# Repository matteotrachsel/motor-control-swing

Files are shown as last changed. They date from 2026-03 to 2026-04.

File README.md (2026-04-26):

# ESP32 Baby Swing Controller

An ESP32-based motor controller for a baby swing. The motor drives a crank
mechanism that converts continuous rotation into a back-and-forth swing motion.
A built-in Progressive Web App (PWA) lets any phone, tablet, or desktop on the
same WiFi network control the swing — no app store required.

The device advertises itself as **`http://rockbox.local`** on your local network.

---

## Features

- **WebSocket real-time control** — low-latency commands and live state sync
  across all connected devices simultaneously
- **Progressive Web App** — installable on Android and iOS home screens; runs
  full-screen with no browser chrome
- **mDNS hostname** — reach the UI at `http://rockbox.local` without
  memorising an IP address
- **Speed control** — adjustable swing speed via a dial (5–80 %)
- **Hard speed cap** — firmware enforces an 80 % PWM ceiling that cannot be
  overridden remotely
- **Rocking patterns** — choose between Steady, Wave, and Lull to vary the
  motion over time
- **Kick-start** — optional boost pulse on startup to overcome crank stiction
- **Auto-stop timer** — configurable run timer (15, 30, 45, or 60 minutes);
  persisted across device restarts
- **Physical button** — hardware toggle on GPIO 18 starts or stops the swing
  without opening the app
- **Manual motor control** — forward/reverse jog in the setup panel, useful
  during installation or maintenance
- **Emergency stop** — always-visible stop button; also accessible via HTTP GET
  `/stop` as a fallback if WebSocket fails
- **WiFi auto-reconnect** — connection is checked every 10 seconds; the ESP32
  reconnects automatically on link loss
- **WiFi setup portal** — captive portal in AP mode for first-time WiFi
  configuration; no hard-coded credentials needed
- **Over-the-air updates** — automatic check against the GitHub release on boot,
  plus a manual upload page at `/update`
- **Dark / light theme** — toggle from the setup panel
- **Motion history** — 30-minute rolling activity graph in the UI

---

## Hardware

### Bill of Materials

| Component | Notes |
|---|---|
| ESP32 development board | Any standard 38-pin ESP32 DevKit |
| L298N motor driver module | Must have the 5 V regulator jumper installed |
| 12 V DC motor | Sized for your swing's crank load |
| 12 V power supply | Current rating matched to motor stall current |
| Connecting wire | — |
| Momentary push button (optional) | For the physical GPIO 18 toggle |

### Wiring

| ESP32 GPIO | L298N pin | Notes |
|---|---|---|
| GPIO 25 | IN1 | Motor direction A |
| GPIO 26 | IN2 | Motor direction B |
| GPIO 27 | ENA | PWM speed signal |
| — | +12 V | From 12 V PSU |
| — | GND | Shared with ESP32 GND |
| VIN (5 V) | 5 V out | L298N onboard regulator powers the ESP32 |
| OUT1 / OUT2 | — | To DC motor terminals |
| GPIO 18 | — | Optional push button to GND (INPUT_PULLUP) |

> All GND pins must be connected together: PSU ground, L298N ground, and ESP32
> ground.

### CAD Files

The `CAD/` folder contains STL and STEP files for 3D-printable mounting
brackets and crank components.

---

## Software Setup

### Prerequisites

- [Visual Studio Code](https://code.visualstudio.com/)
- [PlatformIO IDE extension](https://platformio.org/install/ide?install=vscode)

### Steps

1. **Clone or download** the repository and open the project folder in VS Code.
   PlatformIO will detect `platformio.ini` automatically.

2. **Build and flash** — connect the ESP32 via USB, then click **Upload** in
   the PlatformIO toolbar (or run `pio run --target upload`). PlatformIO
   auto-detects the serial port. To pin a specific port, uncomment the
   `upload_port` line in `platformio.ini`.

3. **Open the Serial Monitor** at 115200 baud to confirm the device boots.

4. **First-time WiFi setup** — on first boot (or after a WiFi reset) the
   device starts in AP mode. See [WiFi Setup](#wifi-setup) below.

> WiFi credentials are stored in NVS (non-volatile storage) and survive
> power cycles. You do not need to hard-code them in `src/main.cpp`.

---

## WiFi Setup

When no WiFi credentials are stored, the device boots into AP (access point)
mode:

1. A network named **`RockBox-Setup`** appears in your WiFi list. Connect
   to it (no password required).
2. A captive portal opens automatically on Android and iOS. If it does not,
   open a browser and go to `http://192.168.4.1`.
3. Tap **Scan** to list nearby networks, select yours, enter the password, and
   tap **Connect & Save**.
4. The device reboots, joins your network, and is accessible at
   `http://rockbox.local`.

To reset WiFi credentials later, open the setup panel (gear icon) in the web
UI and tap **Reset WiFi**, or navigate to `http://rockbox.local/reset-wifi`.

---

## Usage

### Accessing the Web UI

After the ESP32 boots and connects to WiFi, the web interface is available at:

- `http://rockbox.local` — works on most devices without needing the IP
- `http://<ip-address>` — the assigned IP is printed in the Serial Monitor at
  startup

### Installing as a PWA

**Android (Chrome):**
1. Open `http://rockbox.local` in Chrome.
2. Tap the three-dot menu and choose **Add to Home screen** (or tap the
   **Install app** banner that appears at the top of the page).
3. The app opens full-screen from your home screen with no browser bar.

**iOS (Safari):**
1. Open `http://rockbox.local` in Safari.
2. Tap the share button (box with arrow), then **Add to Home Screen**.
3. The app opens full-screen from your home screen.

### Swing Mode

Tap the large circular button to start the swing. The motor runs continuously
in the forward direction; the crank mechanism converts that rotation into
back-and-forth motion. Tap the button again to stop.

The button glows and shows a spinning icon while the motor is running. All
connected devices see the same state in real time.

The physical button on GPIO 18 (if wired) also toggles the swing without
opening the app.

### Speed Dial

The dial sets the motor speed as a percentage (5–80 %). Adjusting it while the
swing is running sends an update immediately (with debouncing). Adjusting it
while the swing is stopped sets the speed for the next start.

### Rocking Patterns

Three patterns are available from the pattern row below the dial:

| Pattern | Behaviour |
|---|---|
| **Steady** | Constant speed — motor runs at exactly the set percentage |
| **Wave** | Sinusoidal variation ±25 % around the target, cycling roughly every 4 seconds |
| **Lull** | Gradual slowdown from full target speed to ~50 % over approximately 5 minutes |

### Auto-stop Timer

Tap a duration button (15, 30, 45, or 60 min) to set a run timer. The
countdown appears in the UI. When the timer elapses the motor stops
automatically. Tap **Off** to disable the timer. The last-set value is
persisted and used for all future sessions.

### Kick-start

Some crank positions require extra torque to get moving. The kick-start feature
fires a brief high-power pulse (60–100 % PWM for 200 ms–1 s) at startup before
dropping to the normal run speed. Configure it in the setup panel (gear icon)
or leave it **Off** if the motor starts reliably without it.

### Manual Control

Open the setup panel (gear icon) and use the **Fwd / Stop / Rev** buttons to
drive the motor directly. This bypasses swing mode and is intended for
installation testing or maintenance. Swing mode is automatically cancelled when
a manual command is sent.

### Emergency Stop

The red **Emergency Stop** button is always visible at the bottom of the
screen. It sends a `stop` command over WebSocket. The HTTP endpoint
`GET /stop` provides the same result if the WebSocket connection is unavailable.

---

## Firmware Updates

### Automatic (on boot)

On every boot the device fetches `version.txt` from the GitHub repository. If
the remote version is newer than the running firmware it downloads
`firmware.bin` from the latest GitHub Release and flashes it automatically,
then reboots.

### Manual upload

Navigate to `http://rockbox.local/update` (credentials: **admin** /
**babyswing** — change `OTA_PASS` in `src/main.cpp` before deploying).

- **Check GitHub for update** — triggers the same automatic check on demand.
- **Upload & Flash** — upload a `.bin` file built with PlatformIO to flash
  immediately.

---

## API / WebSocket Protocol

Connect to `ws://<device-ip>:81`.

### Commands (client → ESP32)

All commands are plain-text strings.

| Command | Arguments | Description |
|---|---|---|
| `heartbeat` | — | Keeps the session alive. The PWA sends this automatically every 15 seconds. |
| `swing_start` | `[speed]` (integer, optional) | Starts the swing. If speed is omitted the last-set swing speed is used. Clamped to 5–80 %. |
| `swing_stop` | — | Stops the motor and clears swing mode. |
| `set_speed` | `speed` (integer) | Updates swing speed. Takes effect immediately if running. Clamped to 5–80 %. |
| `set` | `dir` (`forward`/`reverse`/`stop`) `speed` | Manual motor override. Cancels swing mode. Speed clamped to 0–80 %. |
| `set_timer` | `minutes` (integer, 0–240) | Sets the auto-stop timer duration. 0 disables the timer. |
| `set_kick` | `pct` (0–100) `ms` (50–2000) | Configures the kick-start pulse level and duration. |
| `set_pattern` | `pattern` (`wave`/`steady`/`lull`) | Sets the rocking pattern. |
| `stop` | — | Hard stop — halts the motor and cancels swing mode. |

Examples:

```
swing_start 50
set_speed 60
set forward 30
set_timer 30
set_kick 80 400
set_pattern wave
heartbeat
stop
```

### State Broadcast (ESP32 → all clients)

The ESP32 broadcasts the current state to every connected client after any
command and when clients connect or disconnect.

```json
{
  "swing":     false,
  "speed":     0,
  "dir":       "stop",
  "swingSpd":  40,
  "clients":   1,
  "timerMins": 30,
  "timerSec":  1800,
  "kickPct":   80,
  "kickMs":    400,
  "pattern":   "steady",
  "fw":        34
}
```

| Field | Type | Description |
|---|---|---|
| `swing` | boolean | Whether swing mode is active |
| `speed` | integer | Current motor speed in % (0 when stopped) |
| `dir` | string | Current motor direction: `"forward"`, `"reverse"`, or `"stop"` |
| `swingSpd` | integer | Speed percentage used on the next `swing_start` |
| `clients` | integer | Number of connected WebSocket clients |
| `timerMins` | integer | Configured auto-stop duration in minutes (0 = disabled) |
| `timerSec` | integer | Seconds remaining on the active timer; −1 if no timer is running |
| `kickPct` | integer | Kick-start boost level in % (0 = disabled) |
| `kickMs` | integer | Kick-start pulse duration in milliseconds |
| `pattern` | string | Active rocking pattern: `"steady"`, `"wave"`, or `"lull"` |
| `fw` | integer | Running firmware version number |

---

## Safety Features

### Hard Speed Cap

The firmware clamps all speed values to a maximum of **80 %** PWM duty cycle
via `constrain()` in `applyMotor()`. This cap is enforced in firmware and
cannot be raised through any WebSocket command.

### Auto-stop Timer

The run timer is the primary automatic shutoff mechanism. Set a duration in the
UI; when it elapses the motor stops and the timer resets. If no timer is set the
motor runs until manually stopped.

### WiFi Loss

If the WiFi connection drops, the ESP32 attempts to reconnect every 10 seconds
in the main loop. The motor continues running during a dropout and stops only
if the auto-stop timer fires.

If the ESP32 fails to connect to WiFi at boot, it falls back to AP setup mode.

---

## Architecture

The entire stack runs on the ESP32 — there is no separate server.

| Component | Detail |
|---|---|
| HTTP server | Port 80 — serves the HTML page, PWA manifest, SVG icon, `/stop`, `/update`, `/reset-wifi`, and `/ota-github` endpoints |
| WebSocket server | Port 81 — handles all real-time motor commands and state broadcasts |
| mDNS | Advertises `rockbox.local` on the local network |
| NVS (Preferences) | Persists swing speed, timer, kick-start config, and WiFi credentials across power cycles |
| PWA | HTML, CSS, JavaScript, manifest, and icon are all stored in flash as `PROGMEM` strings — no filesystem required |
| OTA engine | Compares running firmware version against `version.txt` on GitHub; downloads and flashes `firmware.bin` if newer |

### PWM Configuration

| Parameter | Value |
|---|---|
| Channel | 0 |
| Frequency | 5 kHz |
| Resolution | 8-bit (0–255) |

### Compile-time Configuration

The following constants near the top of `src/main.cpp` can be changed before
flashing:

| Constant | Default | Description |
|---|---|---|
| `HOSTNAME` | `"rockbox"` | mDNS hostname (`http://<HOSTNAME>.local`) |
| `FW_VERSION` | integer | Firmware version; increment when creating a release |
| `OTA_USER` | `"admin"` | Username for the `/update` page |
| `OTA_PASS` | `"babyswing"` | Password for the `/update` page — **change this** |
| `AP_SSID` | `"RockBox-Setup"` | SSID broadcast in AP setup mode |

### Runtime Settings (persisted in NVS)

| Setting | Range | Default |
|---|---|---|
| Swing speed | 5–80 % | 40 % |
| Auto-stop timer | 0–240 min | 0 (disabled) |
| Kick-start level | 0–100 % | 0 (disabled) |
| Kick-start duration | 50–2000 ms | 400 ms |
| Rocking pattern | steady / wave / lull | steady |

---

## Automated Builds

A GitHub Actions workflow (`.github/workflows/firmware-release.yml`) builds
`firmware.bin` automatically when a new Git tag is pushed. The resulting binary
is attached to the GitHub Release and served as the OTA target for all devices.

To release a new version:
1. Increment `FW_VERSION` in `src/main.cpp` and update `version.txt` to the
   same number.
2. Commit, tag (`git tag v<N>`), and push the tag.
3. The workflow builds the firmware and creates the release automatically.

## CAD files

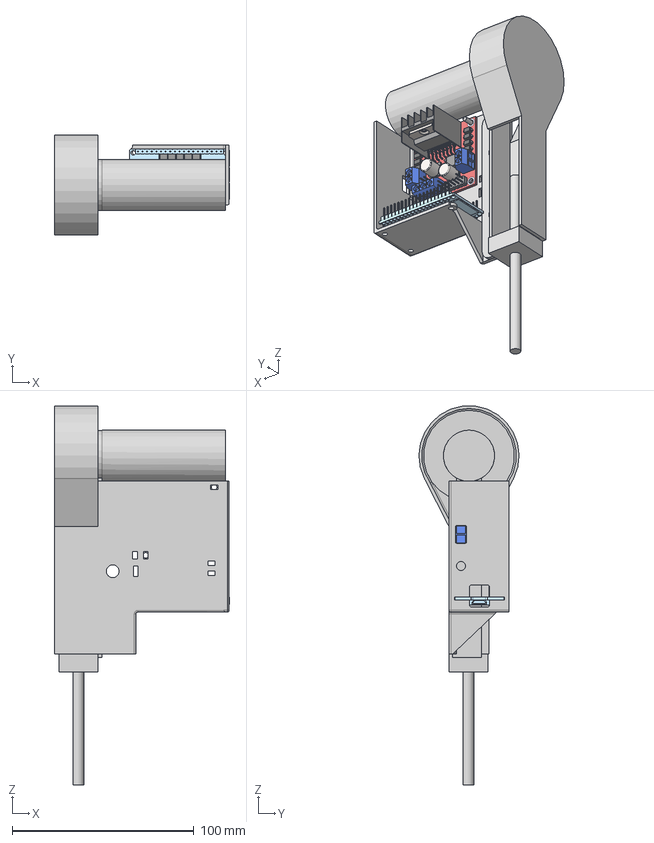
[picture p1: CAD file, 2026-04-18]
CAD/babywippe (Assembly).step
96.2 x 55.1 x 208.3 mm

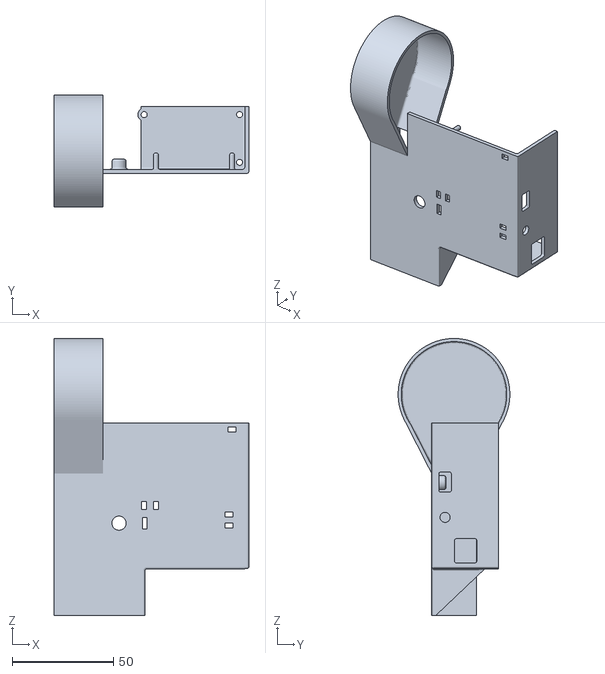
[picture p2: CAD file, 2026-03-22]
CAD/housingFull.stl
96.0 x 55.1 x 136.5

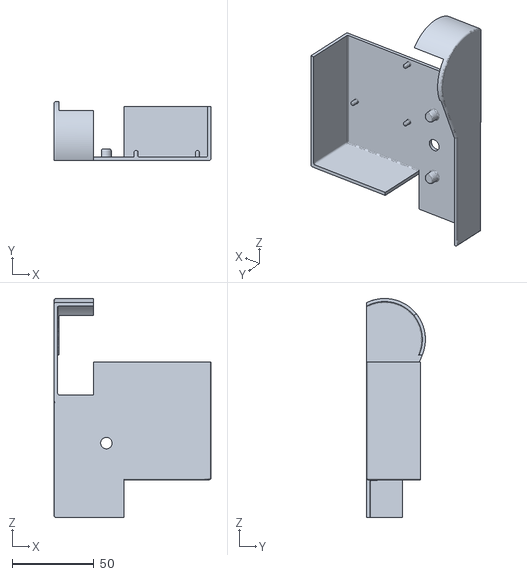
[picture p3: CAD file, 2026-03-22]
CAD/Body1.stl
96.0 x 36.0 x 134.0

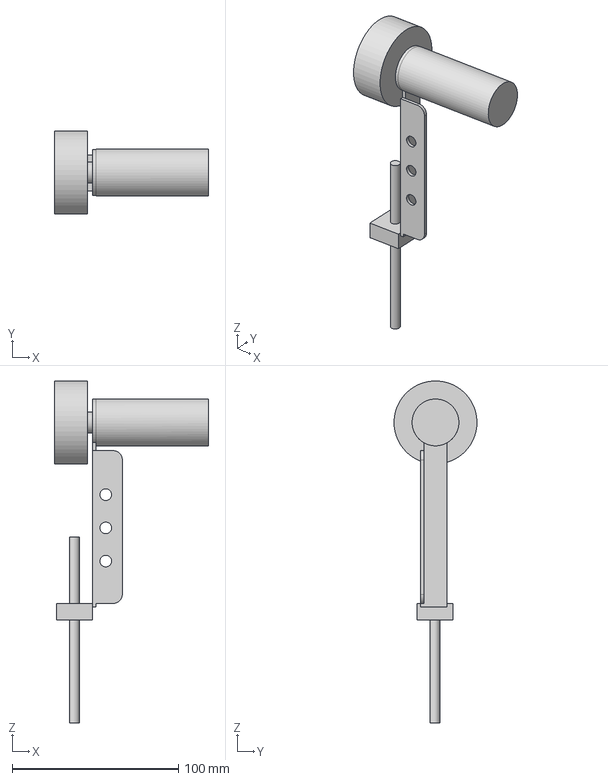
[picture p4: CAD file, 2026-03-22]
CAD/babywippe.step
93.0 x 50.0 x 206.0 mm

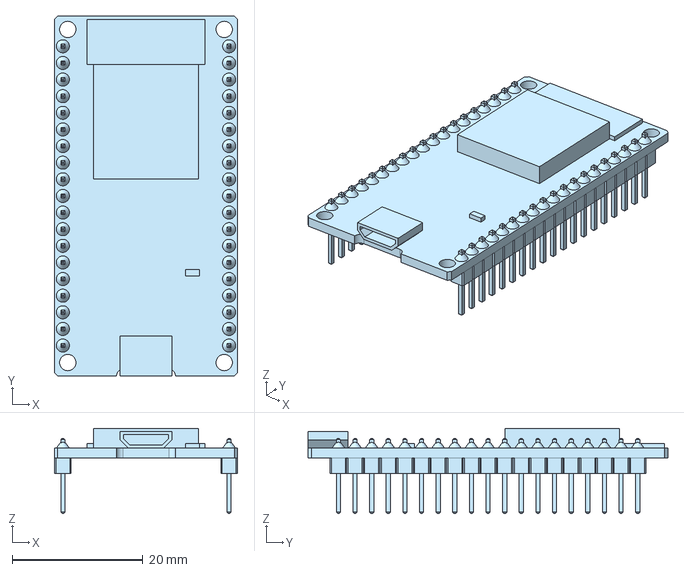
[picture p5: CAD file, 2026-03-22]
CAD/ESP32.step
28.0 x 55.0 x 13.0 mm

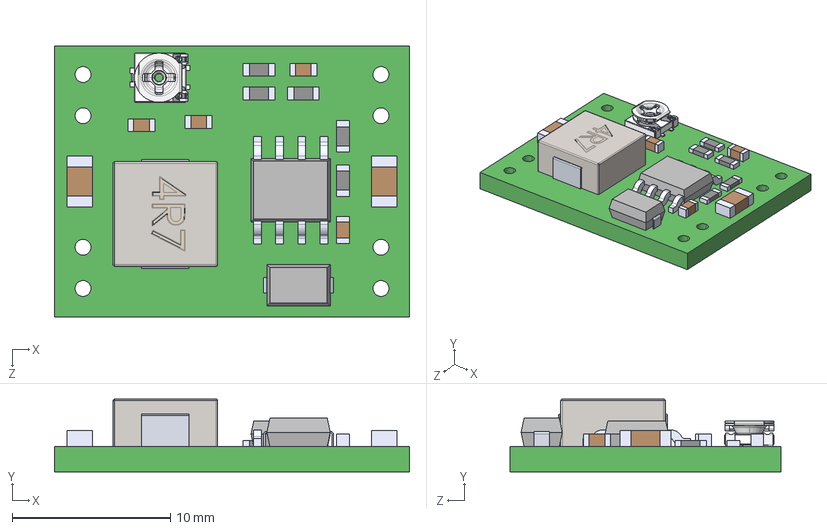
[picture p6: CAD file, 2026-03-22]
CAD/DC_DC_MP1584EN_Step_Down.STEP
22.4 x 4.60 x 17.1 mm
PCB, DC-DC 4.5-28V to 0.8-20V Output 3A MP1584EN Step Down Buck Converter
MP1584EN CHIP, DC-DC 4.5-28V to 0.8-20V Output 3A MP1584EN Step Down Buck Converter
INDUCTOR, DC-DC 4.5-28V to 0.8-20V Output 3A MP1584EN Step Down Buck Converter
SCHOTTKY DIODE, DC-DC 4.5-28V to 0.8-20V Output 3A MP1584EN Step Down Buck Converter
LARGE SMD CAPACITOR, DC-DC 4.5-28V to 0.8-20V Output 3A MP1584EN Step Down Buck Converter x 2
SMD RESISTOR, 104, DC-DC 4.5-28V to 0.8-20V Output 3A MP1584EN Step Down Buck Converter x 4
SMD RESISTOR, 822, DC-DC 4.5-28V to 0.8-20V Output 3A MP1584EN Step Down Buck Converter
SMALL SMD CAPACITOR, DC-DC 4.5-28V to 0.8-20V Output 3A MP1584EN Step Down Buck Converter x 4
POTENTIOMETER, DC-DC 4.5-28V to 0.8-20V Output 3A MP1584EN Step Down Buck Converter

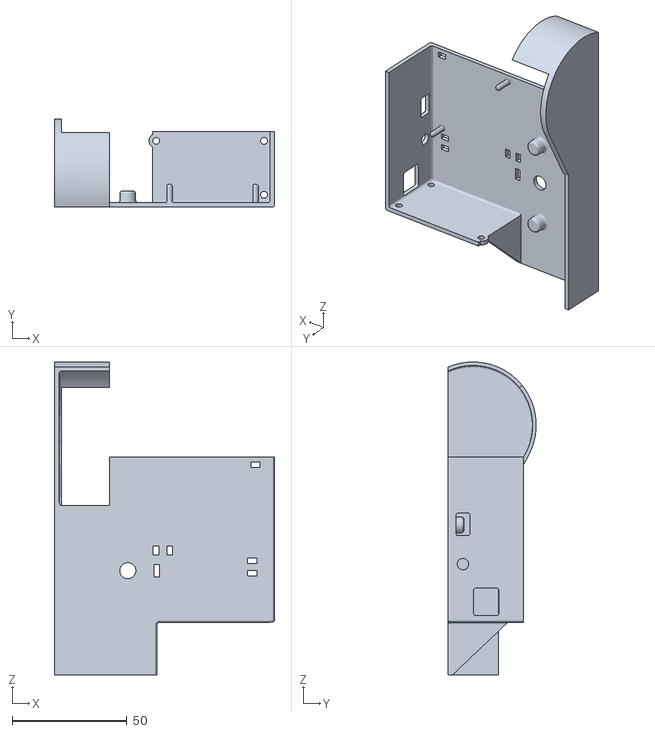
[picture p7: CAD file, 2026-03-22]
CAD/housing_2.stl
96.0 x 38.5 x 136.5

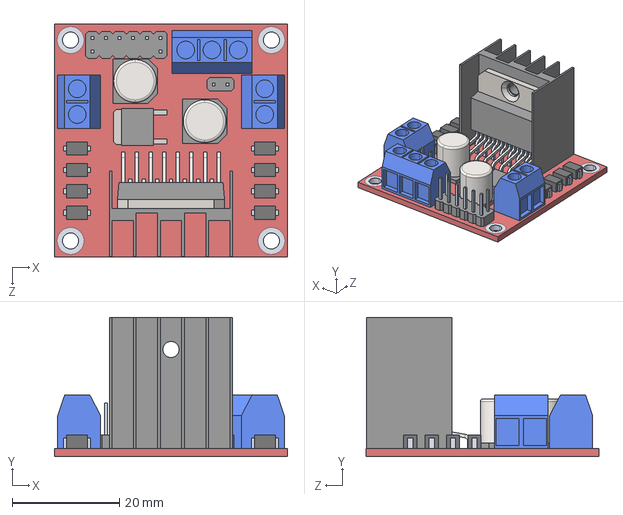
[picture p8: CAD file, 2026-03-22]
CAD/L298N Motor Driver.STEP
43.5 x 26.0 x 43.5 mm

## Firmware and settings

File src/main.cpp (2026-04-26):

/*
 * ============================================================
 *  ESP32 RockBox Controller
 * ============================================================
 *
 *  Motor drives a linear axis via crank — always spins in one
 *  direction. Swing ON = motor runs at set speed. The crank
 *  converts continuous rotation into back-and-forth swing.
 *
 *  Hardware:
 *    12V Adapter  ──▶  L298N +12V & GND
 *    L298N 5V out ──▶  ESP32 VIN  (5V jumper on L298N)
 *    GPIO 25  ──▶  L298N IN1
 *    GPIO 26  ──▶  L298N IN2
 *    GPIO 27  ──▶  L298N ENA  (PWM speed)
 *    OUT1/OUT2 ──▶  DC Motor
 *    All GNDs connected together!
 *
 *  Access from any device on your WiFi:
 *    http://rockbox.local   (or the IP shown in Serial Monitor)
 *
 *  WebSocket port: 81  (HTTP port: 80)
 *
 * ============================================================
 */

#include <Arduino.h>
#include <WiFi.h>
#include <WebServer.h>
#include <WebSocketsServer.h>
#include <ESPmDNS.h>
#include <Preferences.h>
#include <DNSServer.h>
#include <HTTPClient.h>
#include <WiFiClientSecure.h>
#include <HTTPUpdate.h>
#include <Update.h>

// ─── Network config ───────────────────────────────────────────
// WiFi credentials are stored in NVS (set via AP setup portal).
const char *HOSTNAME = "rockbox";      // → http://rockbox.local
const char *AP_SSID = "RockBox-Setup"; // AP mode SSID (open)
// ─────────────────────────────────────────────────────────────

// ─── Firmware version & OTA URLs ─────────────────────────────
// Increment FW_VERSION each release. Commit version.txt with the
// same number to the master branch. Create a GitHub Release and
// upload firmware.bin as an asset named "firmware.bin".
const int FW_VERSION = 35;
const char *GITHUB_VER_URL = "https://raw.githubusercontent.com/matteotrachsel/motor-control-swing/main/version.txt";
const char *GITHUB_BIN_URL = "https://github.com/matteotrachsel/motor-control-swing/releases/latest/download/firmware.bin";
// ─── Manual /update page credentials ─────────────────────────
const char *OTA_USER = "admin";
const char *OTA_PASS = "babyswing"; // change to something personal
// ─────────────────────────────────────────────────────────────

// ─── Motor driver pins ───────────────────────────────────────
const int PIN_IN1 = 25;
const int PIN_IN2 = 26;
const int PIN_ENA = 27; // PWM speed

// ─── Physical toggle button ──────────────────────────────────
const int PIN_BTN = 18; // INPUT_PULLUP — connect one pin pair to GND

// ─── PWM ─────────────────────────────────────────────────────
const int PWM_CH = 0;
const int PWM_FREQ = 5000;
const int PWM_BITS = 8; // 0–255

// ─── Safety limits ───────────────────────────────────────────
const int MAX_SPEED_PCT = 100; // hard cap — never exceeded

// ─── Motor state ─────────────────────────────────────────────
enum MotorDir
{
  MSTOP,
  MFWD,
  MREV
};
int g_spd = 0;
MotorDir g_dir = MSTOP;

// ─── Swing state ─────────────────────────────────────────────
// Motor always runs in one direction — crank handles oscillation.
// Swing ON = motor running; Swing OFF = motor stopped.
bool g_swinging = false;
int g_swingSpd = 40; // % to use when swing starts

// ─── Watchdog ────────────────────────────────────────────────
int g_clients = 0;
ulong g_lastAct = 0;

// ─── Run timer ───────────────────────────────────────────────
int g_timerMins = 0;  // 0 = no timer; >0 = run this many minutes then stop
ulong g_timerEnd = 0; // millis() when timer fires; 0 = no active timer

// ─── Kick-start (start boost) ─────────────────────────
int g_kickPct = 0;   // boost % — 0 = off; typical: 60, 80, 100
int g_kickMs = 400;  // boost duration ms — typical: 200, 400, 600, 1000
ulong g_kickEnd = 0; // millis() when kick pulse ends; 0 = not kicking

// ─── Rocking pattern ──────────────────────────────────
// "steady" = constant speed
// "wave"   = sinusoidal speed variation (rhythmic)
// "lull"   = gradual slowdown to help baby fall asleep
String g_pattern = "steady";
float  g_wavePhase  = 0.0f;  // advances each pattern tick
float  g_lullFactor = 1.0f;  // 1.0 → 0.5 over ~5 min

WebServer httpSrv(80);
WebSocketsServer wsSrv(81);
Preferences prefs;
DNSServer dnsServer;
bool g_apMode = false; // true = running WiFi config portal

// ════════════════════════════════════════════════════════════
//  MOTOR
// ════════════════════════════════════════════════════════════

void applyMotor(MotorDir dir, int pct)
{
  pct = constrain(pct, 0, MAX_SPEED_PCT);
  g_dir = dir;
  g_spd = (dir == MSTOP) ? 0 : pct;

  if (dir == MFWD)
  {
    digitalWrite(PIN_IN1, HIGH);
    digitalWrite(PIN_IN2, LOW);
  }
  else if (dir == MREV)
  {
    digitalWrite(PIN_IN1, LOW);
    digitalWrite(PIN_IN2, HIGH);
  }
  else
  {
    digitalWrite(PIN_IN1, LOW);
    digitalWrite(PIN_IN2, LOW);
  }

  ledcWrite(PWM_CH, (dir == MSTOP) ? 0 : map(pct, 0, 100, 0, 255));
  Serial.printf("[Motor] %s %d%%\n",
                dir == MFWD ? "FWD" : dir == MREV ? "REV"
                                                  : "STOP",
                g_spd);
}

void applyMotorRaw(MotorDir dir, int pct)
{
  pct = constrain(pct, 0, 100);
  g_dir = dir;
  g_spd = (dir == MSTOP) ? 0 : pct;
  if (dir == MFWD)
  {
    digitalWrite(PIN_IN1, HIGH);
    digitalWrite(PIN_IN2, LOW);
  }
  else if (dir == MREV)
  {
    digitalWrite(PIN_IN1, LOW);
    digitalWrite(PIN_IN2, HIGH);
  }
  else
  {
    digitalWrite(PIN_IN1, LOW);
    digitalWrite(PIN_IN2, LOW);
  }
  ledcWrite(PWM_CH, (dir == MSTOP) ? 0 : map(pct, 0, 100, 0, 255));
  Serial.printf("[Kick] RAW FWD %d%%\n", pct);
}

void hardStop()
{
  g_swinging = false;
  g_timerEnd = 0;
  g_kickEnd = 0;
  applyMotor(MSTOP, 0);
}

// ════════════════════════════════════════════════════════════
//  STATE JSON
// ════════════════════════════════════════════════════════════

const char *dirStr(MotorDir d)
{
  return d == MFWD ? "forward" : d == MREV ? "reverse"
                                           : "stop";
}

String stateJSON()
{
  ulong now2 = millis();
  int timerSec = -1;
  if (g_timerEnd != 0 && g_swinging)
    timerSec = (g_timerEnd > now2) ? (int)((g_timerEnd - now2) / 1000) : 0;
  char buf[320];
  snprintf(buf, sizeof(buf),
           "{\"swing\":%s,\"speed\":%d,\"dir\":\"%s\","
           "\"swingSpd\":%d,\"clients\":%d,"
           "\"timerMins\":%d,\"timerSec\":%d,"
           "\"kickPct\":%d,\"kickMs\":%d,"
           "\"pattern\":\"%s\","
           "\"fw\":%d}",
           g_swinging ? "true" : "false",
           g_spd, dirStr(g_dir),
           g_swingSpd, g_clients,
           g_timerMins, timerSec,
           g_kickPct, g_kickMs,
           g_pattern.c_str(),
           FW_VERSION);
  return String(buf);
}

void broadcast()
{
  String s = stateJSON();
  wsSrv.broadcastTXT(s);
}

void saveSettings()
{
  prefs.begin("swing", false);
  prefs.putInt("swingSpd", g_swingSpd);
  prefs.putInt("timerMins", g_timerMins);
  prefs.putInt("kickPct", g_kickPct);
  prefs.putInt("kickMs", g_kickMs);
  prefs.putString("pattern", g_pattern);
  prefs.end();
  Serial.println("[NVS] settings saved");
}

// ─── WiFi credential NVS helpers ─────────────────────────────

bool loadWifiCreds(String &ssid, String &pass)
{
  prefs.begin("wifi", true);
  ssid = prefs.getString("ssid", "");
  pass = prefs.getString("pass", "");
  prefs.end();
  return ssid.length() > 0;
}

void saveWifiCreds(const String &ssid, const String &pass)
{
  prefs.begin("wifi", false);
  prefs.putString("ssid", ssid);
  prefs.putString("pass", pass);
  prefs.end();
  Serial.println("[NVS] WiFi credentials saved");
}

void clearWifiCreds()
{
  prefs.begin("wifi", false);
  prefs.remove("ssid");
  prefs.remove("pass");
  prefs.end();
  Serial.println("[NVS] WiFi credentials cleared");
}

// ─── Helper: escape a string for JSON output ─────────────────
static String jsonEsc(const String &s)
{
  String r;
  r.reserve(s.length());
  for (size_t i = 0; i < s.length(); i++)
  {
    char c = s.charAt(i);
    if (c == '"')
      r += "\\\"";
    else if (c == '\\')
      r += "\\\\";
    else if (c < 0x20)
      r += ' ';
    else
      r += c;
  }
  return r;
}

// ════════════════════════════════════════════════════════════
//  MINI JSON VALUE EXTRACTOR
// ════════════════════════════════════════════════════════════

String jval(const char *json, const char *key)
{
  String s(json);
  String k = String("\"") + key + "\":";
  int i = s.indexOf(k);
  if (i < 0)
    return "";
  i += k.length();
  while (i < (int)s.length() && s[i] == ' ')
    i++;
  bool quoted = (s[i] == '"');
  if (quoted)
  {
    i++;
    int j = s.indexOf('"', i);
    return j < 0 ? "" : s.substring(i, j);
  }
  int j = i;
  while (j < (int)s.length() && s[j] != ',' && s[j] != '}')
    j++;
  return s.substring(i, j);
}

// ════════════════════════════════════════════════════════════
//  WEBSOCKET EVENTS
// ════════════════════════════════════════════════════════════

void onWsEvent(uint8_t num, WStype_t type, uint8_t *payload, size_t length)
{
  if (type == WStype_CONNECTED)
  {
    g_clients++;
    g_lastAct = millis();
    Serial.printf("[WS] +client #%u  total=%d\n", num, g_clients);
    String s = stateJSON();
    wsSrv.sendTXT(num, s);
    broadcast();
    return;
  }
  if (type == WStype_DISCONNECTED)
  {
    g_clients = max(0, g_clients - 1);
    Serial.printf("[WS] -client #%u  total=%d\n", num, g_clients);
    broadcast();
    return;
  }
  if (type != WStype_TEXT)
    return;

  g_lastAct = millis();
  const char *p = (const char *)payload;
  String cmd = jval(p, "cmd");

  if (cmd == "heartbeat")
  {
    // g_lastAct updated above
  }
  else if (cmd == "swing_start")
  {
    String s = jval(p, "speed");
    if (s.length())
      g_swingSpd = constrain(s.toInt(), 5, MAX_SPEED_PCT);
    g_swinging = true;
    g_wavePhase  = 0.0f;   // reset pattern state
    g_lullFactor = 1.0f;
    if (g_timerMins > 0)
      g_timerEnd = millis() + (ulong)g_timerMins * 60000UL;
    else
      g_timerEnd = 0;
    if (g_kickPct > 0 && g_kickPct > g_swingSpd)
    {
      applyMotorRaw(MFWD, g_kickPct);
      g_kickEnd = millis() + (ulong)g_kickMs;
      Serial.printf("[Kick] %d%% for %dms → run %d%%\n", g_kickPct, g_kickMs, g_swingSpd);
    }
    else
    {
      g_kickEnd = 0;
      applyMotor(MFWD, g_swingSpd);
    }
    broadcast();
    Serial.printf("[Swing] START  spd=%d%%  timer=%dmin\n", g_swingSpd, g_timerMins);
  }
  else if (cmd == "swing_stop")
  {
    hardStop();
    broadcast();
    Serial.println("[Swing] STOP");
  }
  else if (cmd == "set")
  {
    // Manual override (useful for setup / testing direction)
    g_swinging = false;
    String d = jval(p, "dir");
    String s = jval(p, "speed");
    MotorDir dir = MSTOP;
    if (d == "forward")
      dir = MFWD;
    else if (d == "reverse")
      dir = MREV;
    applyMotor(dir, s.length() ? s.toInt() : 0);
    broadcast();
  }
  else if (cmd == "set_speed")
  {
    String s = jval(p, "speed");
    if (s.length())
    {
      g_swingSpd = constrain(s.toInt(), 5, MAX_SPEED_PCT);
      if (g_swinging)
        applyMotor(MFWD, g_swingSpd);
      saveSettings();
      broadcast();
    }
  }
  else if (cmd == "stop")
  {
    hardStop();
    broadcast();
  }
  else if (cmd == "set_timer")
  {
    String m = jval(p, "minutes");
    if (m.length())
    {
      g_timerMins = constrain(m.toInt(), 0, 240);
      if (g_swinging)
      {
        if (g_timerMins > 0)
          g_timerEnd = millis() + (ulong)g_timerMins * 60000UL;
        else
          g_timerEnd = 0;
      }
      saveSettings();
      broadcast();
      Serial.printf("[Timer] set to %d min\n", g_timerMins);
    }
  }
  else if (cmd == "set_kick")
  {
    String kPct = jval(p, "pct");
    String kMs = jval(p, "ms");
    if (kPct.length())
      g_kickPct = constrain(kPct.toInt(), 0, 100);
    if (kMs.length())
      g_kickMs = constrain(kMs.toInt(), 50, 2000);
    saveSettings();
    broadcast();
    Serial.printf("[Kick] set pct=%d  ms=%d\n", g_kickPct, g_kickMs);
  }
  else if (cmd == "set_pattern")
  {
    String pat = jval(p, "pattern");
    if (pat == "wave" || pat == "steady" || pat == "lull")
    {
      g_pattern    = pat;
      g_wavePhase  = 0.0f;
      g_lullFactor = 1.0f;
      saveSettings();
      broadcast();
      Serial.printf("[Pattern] set to %s\n", g_pattern.c_str());
    }
  }
}

// ════════════════════════════════════════════════════════════
//  WEB UI  — Progressive Web App (installable on Android/iOS)
// ════════════════════════════════════════════════════════════
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
void loop()
{
  // ── AP mode: only serve the config portal ─────────────────
  if (g_apMode)
  {
    dnsServer.processNextRequest();
    httpSrv.handleClient();
    return;
  }

  // ── Normal mode ────────────────────────────────────────────
  static ulong wifiCheck = 0;
  ulong now = millis();

  // WiFi watchdog — non-blocking, checked every 10 s
  if (now - wifiCheck > 10000)
  {
    wifiCheck = now;
    if (WiFi.status() != WL_CONNECTED)
    {
      Serial.println("[WiFi] Lost — reconnecting...");
      WiFi.reconnect();
    }
  }

  httpSrv.handleClient();
  wsSrv.loop();
  now = millis();

  // Physical button: debounced toggle (50 ms) — starts or stops swing
  static bool  btnLast    = HIGH;
  static ulong btnDebTime = 0;
  bool btnNow = digitalRead(PIN_BTN);
  if (btnNow != btnLast) btnDebTime = now;
  if (now - btnDebTime > 50 && btnNow == LOW && btnLast != LOW)
  {
    // Falling edge confirmed after debounce
    if (g_swinging)
    {
      hardStop();
      Serial.println("[BTN] Stop");
    }
    else
    {
      g_swinging   = true;
      g_wavePhase  = 0.0f;
      g_lullFactor = 1.0f;
      g_timerEnd   = g_timerMins > 0 ? now + (ulong)g_timerMins * 60000UL : 0UL;
      applyMotor(MFWD, g_swingSpd);
      Serial.printf("[BTN] Start spd=%d pattern=%s\n", g_swingSpd, g_pattern.c_str());
    }
    broadcast();
  }
  btnLast = btnNow;

  // Run-timer: stop motor when the user-set duration elapses.
  // Motor keeps running after phone disconnects until timer fires.
  if (g_swinging && g_timerEnd != 0 && now >= g_timerEnd)
  {
    Serial.println("[Timer] Duration elapsed — stopping motor");
    hardStop();
    broadcast();
  }
  // Kick-start: drop from boost PWM to run speed when pulse window ends.
  if (g_kickEnd != 0 && now >= g_kickEnd)
  {
    g_kickEnd = 0;
    if (g_swinging)
    {
      applyMotor(MFWD, g_swingSpd);
      Serial.printf("[Kick] done — running at %d%%\n", g_swingSpd);
    }
  }

  // Pattern tick — runs every 500 ms while swinging (not during kick)
  static ulong patternTick = 0;
  if (g_swinging && g_kickEnd == 0 && now - patternTick >= 500)
  {
    patternTick = now;
    if (g_pattern == "wave")
    {
      // Sinusoidal variation: speed oscillates ±25% around target, period ~4 s
      g_wavePhase += 0.785f; // π/4 per tick → 8 ticks = 4 s full cycle
      float factor = 0.75f + 0.25f * sinf(g_wavePhase);
      int spd = constrain((int)(g_swingSpd * factor), 5, MAX_SPEED_PCT);
      applyMotor(MFWD, spd);
    }
    else if (g_pattern == "lull")
    {
      // Gradual decay: full speed → 50% over ~5 min (600 ticks × 500 ms)
      g_lullFactor -= 0.000833f;
      if (g_lullFactor < 0.5f) g_lullFactor = 0.5f;
      int spd = constrain((int)(g_swingSpd * g_lullFactor), 5, MAX_SPEED_PCT);
      applyMotor(MFWD, spd);
    }
    // steady: no speed change needed
  }
}

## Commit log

2026-03-22 update firmeware
    [Body1.stl, DC_DC_MP1584EN_Step_Down.STEP, ESP32.step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]
2026-03-22 update led
2026-03-22 chore: bump to v23 [skip ci]
    [main.cpp]
2026-04-18 update max speed
    [babywippe (Assembly).step]
2026-04-19 chore: bump to v34 [skip ci]
    [main.cpp]
2026-04-26 Update README with accurate features, corrected hostname, and complete API docs
    - Fix hostname from babyswing.local to rockbox.local (matches firmware constant)
    - Remove inaccurate 30-second heartbeat watchdog claim (not implemented in code)
    - Add rocking patterns (Steady, Wave, Lull) with behaviour descriptions
    - Add kick-start feature documentation
    - Add auto-stop timer section (the actual automatic shutoff mechanism)
    - Add physical button (GPIO 18) to hardware wiring table and usage section
    - Add WiFi setup portal section (AP mode, RockBox-Setup SSID, captive portal)
    - Add firmware update section (automatic OTA on boot + manual /update page)
    - Add OTA security note to change default crede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
2026-04-26 chore: bump to v35 [skip ci]
    [main.cpp]
